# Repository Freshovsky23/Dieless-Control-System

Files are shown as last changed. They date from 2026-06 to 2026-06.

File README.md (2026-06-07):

# Dieless - Automated Wire Drawing Control System 🧵⚙️⚡

An advanced embedded control system designed for a **Dieless Wire Drawing Machine** engineering project. This system coordinates independent dual-stepper motor velocity profiles, features real-time analog micro-adjustments, and utilizes a complete local Human-Machine Interface (HMI).

Developed under the auspices of the **"CREATIVE" Student Science Club**.

---

## 📺 Project Presentation & Demo

Watch the system in action on YouTube:



*Click the badge above to watch the project implementation and physical mechanical execution details.*

---

## 🚀 System Features

* **High-Performance Jitter-Free Engine:** Implements a non-blocking microsecond phase-accumulation scheduler capable of driving dual A4988 stepper drivers independently without timing drift.
* **Velocity Profiling (Ramp Rate):** Integrated linear acceleration and deceleration profiling (2000 Hz/s rate) protecting motors from stalling or losing synchronization during sudden load changes.
* **Real-Time Trim Adjustment:** Dual-potentiometer sampling with 12-bit ADC mapping, providing a precision $\pm5\%$ velocity override overlay on-the-fly.
* **4x4 Matrix Keypad Configuration:** Full operational control board layout using an asynchronous multi-state input buffer for entering specific base frequencies (Hz).
* **Optimized I2C HMI Display:** Formatted 20x4 LCD frame architecture running on a high-speed 400kHz I2C bus clock to eliminate screen update blocking latencies.

---

## 🛠️ Hardware & PCB Design

The control system has been migrated from breadboard prototyping to a dedicated, custom-designed PCB tailored for high-frequency signal switching and heavy motor current distribution. 

### 📐 PCB View (3D Render)
The board architecture implements strict physical isolation between the high-current motor power rails (VMOT) and the sensitive analog/I2C traces to completely eliminate electromagnetic interference and noise injection.

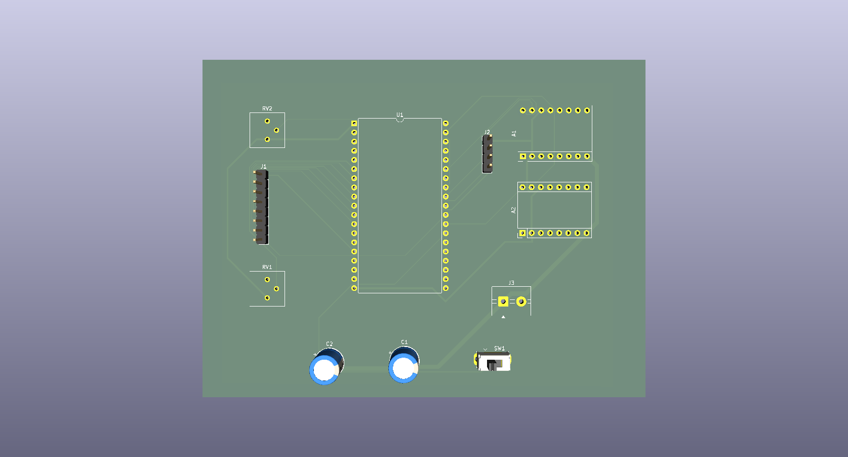
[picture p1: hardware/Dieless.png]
Dieless Control PCB 3D Render


---

## 🔌 Complete Hardware Pin Mapping (Pinout)

To ensure proper hardware replication, connect the peripheral components to the ESP32 microcontroller precisely as outlined in the engineering reference tables below:

### 1. Actuators & Control Interfaces
| ESP32 GPIO Pin | Component Peripheral | Hardware Functionality / Description | Suggested Track Width |
| :---: | :--- | :--- | :---: |
| **+5V / VIN** | Main Logic Rail | Core power for driver logic and LCD module | **0.50 mm** |
| **+3.3V** | Analog Rail | Clean reference voltage for ADC potentiometers | **0.50 mm** |
| **VMOT (24V)** | A4988 Power Supply | High-current power for stepper motor coils | 🔥 **1.20 mm** |
| **GND** | System Common | Solid Ground Plane (Bottom Copper Zone) | *Copper Zone* |
| **GPIO 18** | Stepper Driver 1 (A4988) | **STEP** – Motor 1 Pulse Generation Line (Wire Feeding) | 0.25 mm |
| **GPIO 19** | Stepper Driver 1 (A4988) | **DIR** – Motor 1 Directional Logic Level Control | 0.25 mm |
| **GPIO 23** | Stepper Driver 2 (A4988) | **STEP** – Motor 2 Pulse Generation Line (Wire Drawing) | 0.25 mm |
| **GPIO 16** | Stepper Driver 2 (A4988) | **DIR** – Motor 2 Directional Control (*Safe Non-Bootstrap Pin*) | 0.25 mm |
| **GPIO 34** | Potentiometer 1 | **Analog Input** – Motor 1 Real-time Speed Trim Override | 0.25 mm |
| **GPIO 35** | Potentiometer 2 | **Analog Input** – Motor 2 Real-time Speed Trim Override | 0.25 mm |
| **GPIO 4** | SPDT Toggle Switch | **Digital Input (Internal Pullup)** – Active Motor Selection Editor | 0.25 mm |

### 2. 4x4 Membrane Keypad Matrix Connections
| ESP32 GPIO Pin | Keypad Ribbon Pin | Matrix Row / Column Designation | Suggested Track Width |
| :---: | :---: | :--- | :---: |
| **GPIO 13** | Pin 1 | **ROW 1** (Handles keys: 1, 2, 3, A) | 0.25 mm |
| **GPIO 14** | Pin 2 | **ROW 2** (Handles keys: 4, 5, 6, B) | 0.25 mm |
| **GPIO 27** | Pin 3 | **ROW 3** (Handles keys: 7, 8, 9, C) | 0.25 mm |
| **GPIO 26** | Pin 4 | **ROW 4** (Handles keys: \*, 0, #, D) | 0.25 mm |
| **GPIO 25** | Pin 5 | **COL 1** (Handles keys: 1, 4, 7, \*) | 0.25 mm |
| **GPIO 33** | Pin 6 | **COL 2** (Handles keys: 2, 5, 8, 0) | 0.25 mm |
| **GPIO 32** | Pin 7 | **COL 3** (Handles keys: 3, 6, 9, #) | 0.25 mm |
| **GPIO 17** | Pin 8 | **COL 4** (Handles keys: A, B, C, D) | 0.25 mm |

### 3. Display Peripherals & Bus Communication
| ESP32 GPIO Pin | Module / Controller | Bus Line Designation | Suggested Track Width |
| :---: | :--- | :--- | :---: |
| **GPIO 21** | I2C LCD 20x4 (PCF8574) | **SDA** – Serial Data Communication Bus | 0.25 mm |
| **GPIO 22** | I2C LCD 20x4 (PCF8574) | **SCL** – Serial Clock Bus (Configured to 400kHz Fast Mode) | 0.25 mm |

---

## ⌨️ Control Panel HMI Reference

### Keypad 4x4 Layout Matrix

| Key | Core Function | Operational Description |
| :---: | :--- | :--- |
| **`0` – `9`** | **Numeric Entry** | Inputs target step frequency values (Safe bounded range: `0` – `9999` Hz). |
| **`D`** | **Direction Stage** | Toggles the pending rotational direction profile buffer layout between `[CW]` and `[CCW]`. |
| **`#`** | **ENTER / Commit** | Flushes the staged parameters, saving target velocity and setting hardware direction pins. |
| **`*`** | **Backspace** | Removes the terminal character from the active screen buffer string. |
| **`C`** | **Clear Buffer** | Instantly wipes the temporary keyboard data input buffer. |
| **`A`** | **START Machine** | Global execution trigger. Smoothly ramps up both stepper lines to target run frequencies. |
| **`B`** | **STOP Machine** | E-Stop equivalent software override. Instantly cuts execution pulses and triggers safe deceleration. |

### LCD 20x4 Screen Topology Reference
The user interface handles full frame updates seamlessly asynchronously. The display grid mapping topology layout runs as follows:

```text
+------------------------------------+
|M1: [BaseHz] |T:[Trim%] |[ActiveDir]| -> Line 1: Wire Feeding Motor Telemetry
|M2: [BaseHz] |T:[Trim%] |[ActiveDir]| -> Line 2: Wire Drawing Motor Telemetry
|Input: [EditorBuffer]   [PendingDir]| -> Line 3: Live Input HMI Keypad Buffer
|[MachineStatus] | Ed: [TargetMotor] | -> Line 4: System Operational Status
+------------------------------------+
📂 Repository Structure
Plaintext
├── firmware/              # ESP32 Core Control Source Code (C++/Arduino)
│   ├── src/
│   │   └── main.cpp
│   └── platformio.ini
├── hardware/              # KiCad EDA Project Files & Manufacturing Exports
│   ├── dieless-control.kicad_pro
│   ├── dieless-control.kicad_sch
│   ├── dieless-control.kicad_pcb
│   └── Dieless.png        # 3D Render preview of the custom PCB layout
└── README.md              # Main project documentation
👤 Author
Developer: @Freshovsky23

Contact: Heilman.Wiktor23@gmail.com

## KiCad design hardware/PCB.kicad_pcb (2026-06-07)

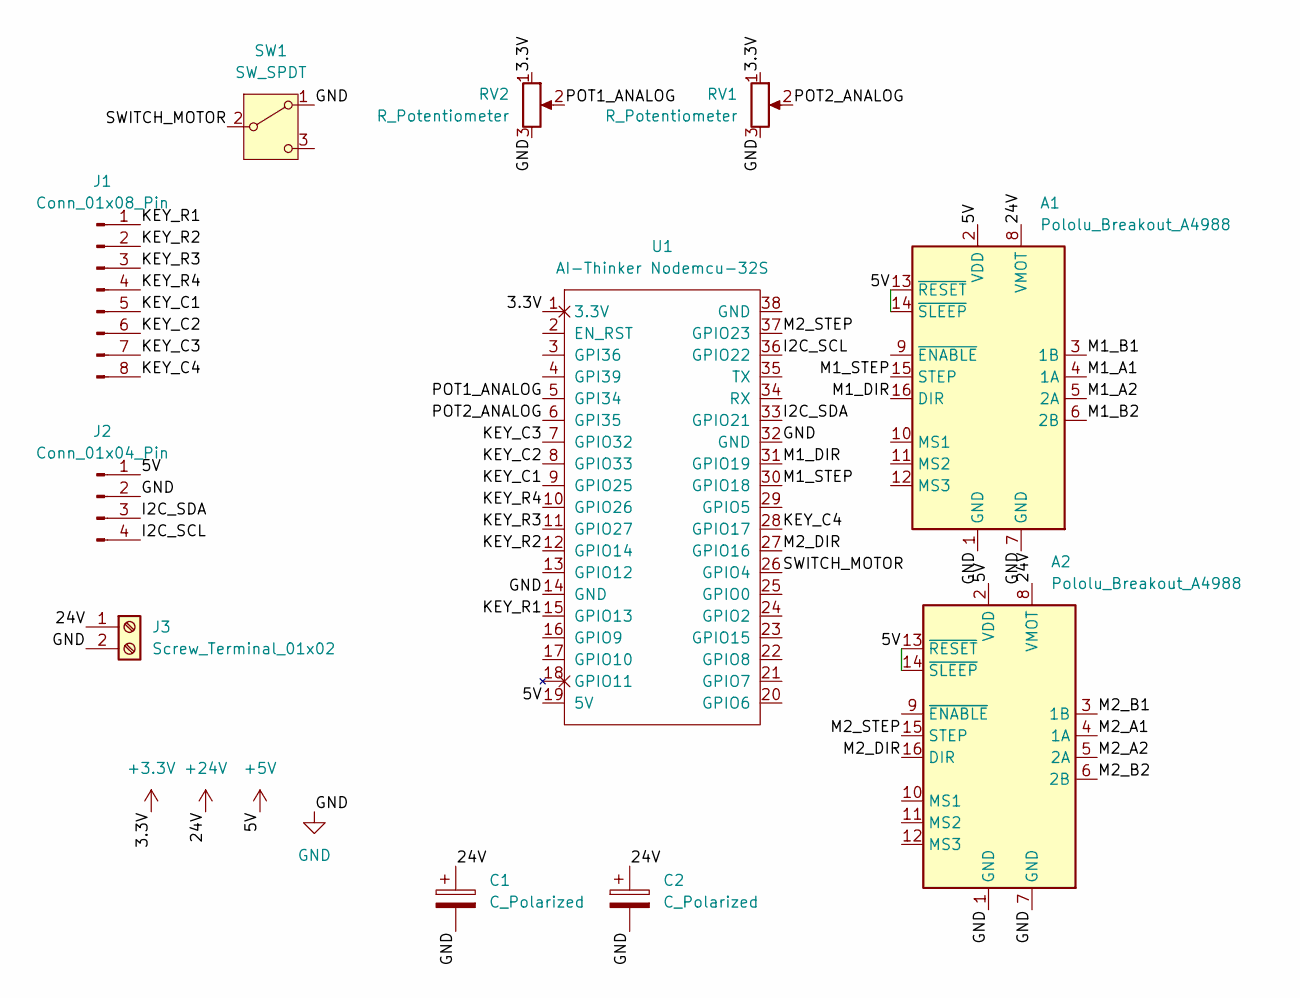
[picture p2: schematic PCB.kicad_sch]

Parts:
A1, A2: Pololu_Breakout_A4988; Pololu_Breakout-16_15.2x20.3mm
C1, C2: C_Polarized; CP_Radial_D8.0mm_P3.50mm
J1: Conn_01x08_Pin; PinHeader_1x08_P2.54mm_Vertical
J2: Conn_01x04_Pin; PinHeader_1x04_P2.54mm_Vertical
J3: Screw_Terminal_01x02; TerminalBlock_MaiXu_MX126-5.0-02P_1x02_P5.00mm
RV1, RV2: R_Potentiometer; Potentiometer_Bourns_3386P_Vertical
SW1: SW_SPDT; SW_Slide_SPDT_Straight_CK_OS102011MS2Q
U1: AI-Thinker Nodemcu-32S; ai-thinker nodemcu-32s

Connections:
+3.3V: RV1.1, RV2.1, U1.1 (3.3V)
+5V: A1.2 (VDD), A1.13 (~RESET), A1.14 (~SLEEP), A2.2 (VDD), A2.13 (~RESET), A2.14 (~SLEEP), J2.1, U1.19 (5V)
+24V: A1.8 (VMOT), A2.8 (VMOT), C1.1, C2.1, J3.1
/I2C_SCL: J2.4, U1.36 (GPIO22)
/I2C_SDA: J2.3, U1.33 (GPIO21)
/KEY_C1: J1.5, U1.9 (GPIO25)
/KEY_C2: J1.6, U1.8 (GPIO33)
/KEY_C3: J1.7, U1.7 (GPIO32)
/KEY_C4: J1.8, U1.28 (GPIO17)
/KEY_R1: J1.1, U1.15 (GPIO13)
/KEY_R2: J1.2, U1.12 (GPIO14)
/KEY_R3: J1.3, U1.11 (GPIO27)
/KEY_R4: J1.4, U1.10 (GPIO26)
/M1_A1: A1.4 (1A)
/M1_A2: A1.5 (2A)
/M1_B1: A1.3 (1B)
/M1_B2: A1.6 (2B)
/M1_DIR: A1.16 (DIR), U1.31 (GPIO19)
/M1_STEP: A1.15 (STEP), U1.30 (GPIO18)
/M2_A1: A2.4 (1A)
/M2_A2: A2.5 (2A)
/M2_B1: A2.3 (1B)
/M2_B2: A2.6 (2B)
/M2_DIR: A2.16 (DIR), U1.27 (GPIO16)
/M2_STEP: A2.15 (STEP), U1.37 (GPIO23)
/POT1_ANALOG: RV2.2, U1.5 (GPI34)
/POT2_ANALOG: RV1.2, U1.6 (GPI35)
/SWITCH_MOTOR: SW1.2 (B), U1.26 (GPIO4)
GND: A1.1 (GND), A1.7 (GND), A2.1 (GND), A2.7 (GND), C1.2, C2.2, J2.2, J3.2, RV1.3, RV2.3, SW1.1 (A), U1.14 (GND), U1.32 (GND)

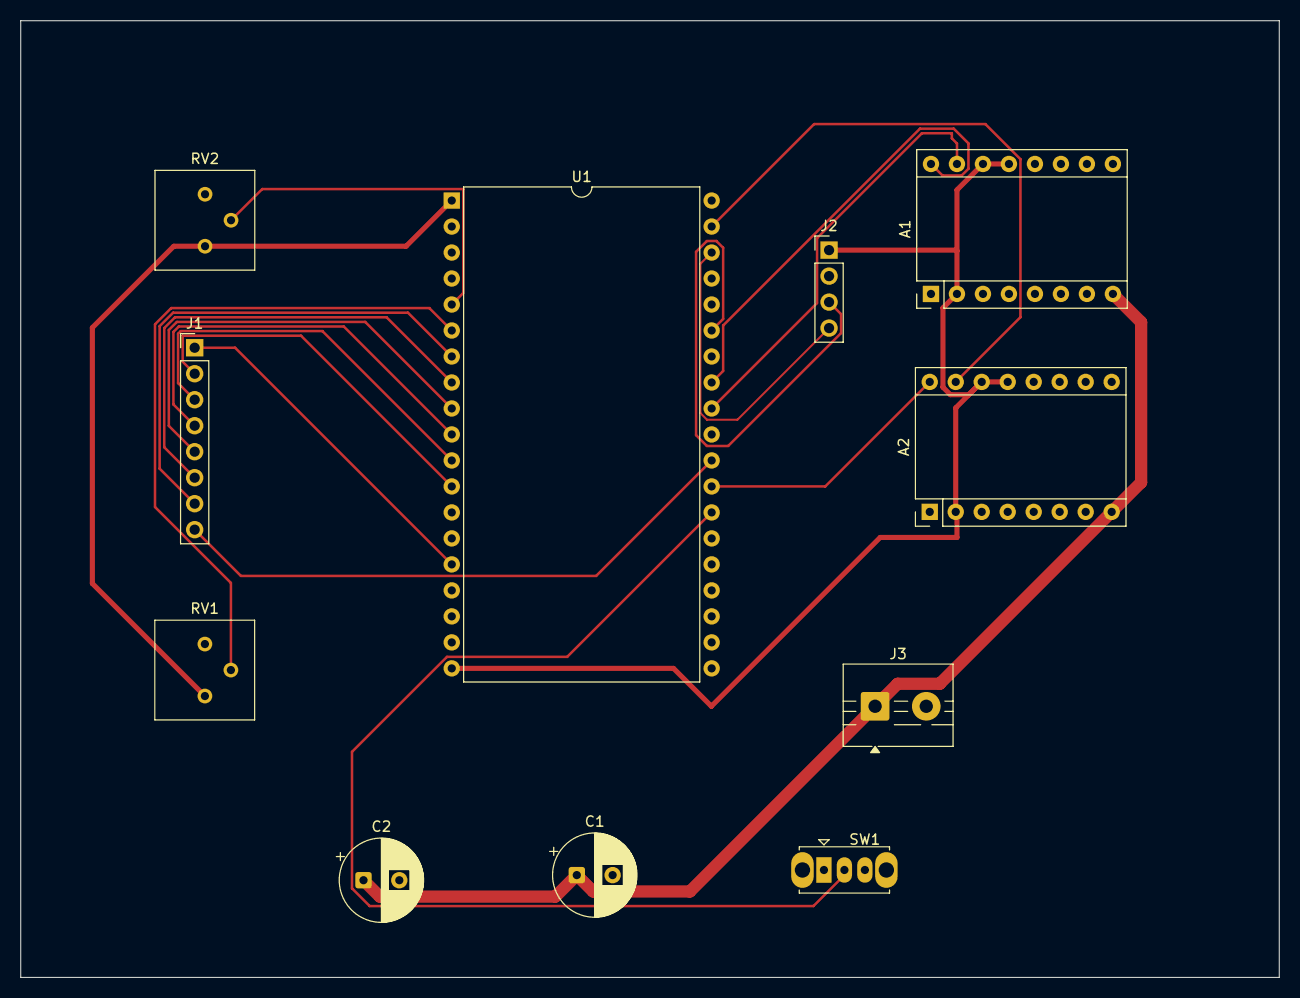
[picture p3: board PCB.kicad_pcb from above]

Board: 2 copper layers, 123.0 x 93.5 mm, 11 parts (0 on the bottom side), 21 nets.

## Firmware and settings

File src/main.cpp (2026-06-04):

#include <Arduino.h>           // Include the core Arduino framework libraries
#include <Wire.h>              // Include the I2C communication library for LCD control
#include <LiquidCrystal_I2C.h> // Include the library for I2C Liquid Crystal Displays
#include <Keypad.h>            // Include the matrix keypad interface library

// --- PIN CONFIGURATION ---
const int POT1_PIN = 34;       // Analog input pin for Potentiometer 1 (Motor 1 speed trim)
const int POT2_PIN = 35;       // Analog input pin for Potentiometer 2 (Motor 2 speed trim)
const int SWITCH_PIN = 4;      // Digital input pin for the motor selection toggle switch

const int STEP_PIN_1 = 18;     // Digital output pin for Motor 1 STEP signal (A4988 driver)
const int DIR_PIN_1  = 19;     // Digital output pin for Motor 1 DIRECTION signal (A4988 driver)
const int STEP_PIN_2 = 23;     // Digital output pin for Motor 2 STEP signal (A4988 driver)
const int DIR_PIN_2  = 16;     // Digital output pin for Motor 2 DIRECTION signal (GPIO16 replaces bootstrap GPIO5)

// --- 4x4 MEMBRANE KEYPAD CONFIGURATION ---
const byte ROWS = 4;           // Define the number of rows on the keypad matrix
const byte COLS = 4;           // Define the number of columns on the keypad matrix
char keys[ROWS][COLS] = {      // Define the key map layout corresponding to the physical matrix
  {'1','2','3','A'},           // Row 0 key definitions (Numbers 1-3, Command A -> START)
  {'4','5','6','B'},           // Row 1 key definitions (Numbers 4-6, Command B -> STOP)
  {'7','8','9','C'},           // Row 2 key definitions (Numbers 7-9, Command C -> CLEAR)
  {'*','0','#','D'}            // Row 3 key definitions (Backspace, Zero, Enter, Command D -> TOGGLE DIR)
};                             // End of keys matrix definition

byte rowPins[ROWS] = {13, 14, 27, 26}; // ESP32 GPIO pins connected to the keypad row lines
byte colPins[COLS] = {25, 33, 32, 17}; // ESP32 GPIO pins connected to the keypad column lines

Keypad keypad = Keypad(makeKeymap(keys), rowPins, colPins, ROWS, COLS); // Initialize Keypad instance with layout and pins
LiquidCrystal_I2C lcd(0x27, 20, 4);                                    // Initialize LCD instance at I2C address 0x27, 20x4 characters

// --- PROCESS VARIABLES ---
int baseV1 = 500;              // Target base frequency for Motor 1 in Hz (Steps per second)
int baseV2 = 500;              // Target base frequency for Motor 2 in Hz (Steps per second)
String inputBuffer = "";       // String buffer to accumulate numeric characters from the keypad

bool targetDir1 = true;        // Hardware direction state for Motor 1 (true = CW / HIGH, false = CCW / LOW)
bool targetDir2 = true;        // Hardware direction state for Motor 2 (true = CW / HIGH, false = CCW / LOW)
bool bufferDir  = true;        // Staged/pending direction state for the currently selected motor inside the editor

bool systemRunning = false;    // Global execution flag tracking machine state (false=STOP, true=RUN)
bool prevRunning   = false;    // Flag storing previous execution state to detect positive edge trigger
int prevSwitchState = -1;      // Variable to track changes in the hardware toggle switch state

// --- ACCELERATION / DECELERATION RAMP ---
int currentV1 = 0;             // Instantaneous velocity profile step for Motor 1 (Hz)
int currentV2 = 0;             // Instantaneous velocity profile step for Motor 2 (Hz)
const int RAMP_STEP        = 10; // Velocity delta increment per ramp execution interval (Hz)
const int RAMP_INTERVAL_MS = 5;  // Fixed millisecond interval separating velocity ramp step updates
unsigned long lastRampTime = 0; // Timestamp tracking the last millisecond execution of the ramp logic

// --- NON-BLOCKING TIMERS ---
unsigned long lastDisplayUpdate = 0; // Timestamp tracking the last millisecond update of the LCD interface
unsigned long lastStepTime1     = 0; // Timestamp tracking the exact microsecond execution of Motor 1's last step
unsigned long lastStepTime2     = 0; // Timestamp tracking the exact microsecond execution of Motor 2's last step

// Converts step frequency (Hz) to a non-blocking pulse period interval in microseconds
unsigned long speedToInterval(int speedHz) {
    if (speedHz <= 0) return 0;      // Return zero interval if target velocity is non-positive to stall motor
    return 1000000UL / speedHz;      // Calculate microsecond period using Unsigned Long literal to prevent overflow
}                                    // End of speedToInterval function

// ─────────────────────────────────────────────────────────────────────────────
void setup() {                       // Hardware and peripheral initialization phase
    Serial.begin(115200);            // Open hardware serial port at high-speed 115200 baud for debugging

    pinMode(POT1_PIN,   INPUT);      // Configure Potentiometer 1 pin as high-impedance analog input
    pinMode(POT2_PIN,   INPUT);      // Configure Potentiometer 2 pin as high-impedance analog input
    pinMode(SWITCH_PIN, INPUT_PULLUP); // Configure toggle switch pin with internal pull-up resistor active

    pinMode(STEP_PIN_1, OUTPUT);     // Configure Motor 1 step line as digital push-pull output
    pinMode(DIR_PIN_1,  OUTPUT);     // Configure Motor 1 direction line as digital push-pull output
    pinMode(STEP_PIN_2, OUTPUT);     // Configure Motor 2 step line as digital push-pull output
    pinMode(DIR_PIN_2,  OUTPUT);     // Configure Motor 2 direction line as digital push-pull output

    digitalWrite(DIR_PIN_1, targetDir1 ? HIGH : LOW); // Write default rotational direction to Motor 1 driver hardware
    digitalWrite(DIR_PIN_2, targetDir2 ? LOW : HIGH); // HARDWARE FIX: Inverted Motor 2 pin mapping to synchronize direction

    lcd.init();                      // Wake up and execute internal initialization routine for the I2C LCD
    lcd.backlight();                 // Enable the LED backlight power rail on the LCD module

    Wire.setClock(400000);           // Increase I2C bus speed to 400kHz to minimize blocking overhead during step cycles

    lcd.setCursor(0, 0); lcd.print("V1:      |T:    |    "); // Render static template framework for Line 0 (Speed, Trim, Direction)
    lcd.setCursor(0, 1); lcd.print("V2:      |T:    |    "); // Render static template framework for Line 1 (Speed, Trim, Direction)
    lcd.setCursor(0, 2); lcd.print("Input:              "); // Clear template line 2 to prevent double brackets
    lcd.setCursor(0, 3); lcd.print("STOP| Ed: ----------"); // Render static template framework for Line 3 (System Status + selection)
}                                    // End of setup function

// ─────────────────────────────────────────────────────────────────────────────
void loop() {                        // Main cyclical program execution thread
    char key         = keypad.getKey();         // Poll the keypad matrix controller for asynchronous key press events
    int  switchState = digitalRead(SWITCH_PIN); // Read physical toggle switch state (LOW = Motor 1, HIGH = Motor 2)

    // ── SWITCH STATE MONITORING & BUFFER SYNC ─────────────────────────────
    if (switchState != prevSwitchState) {       // Evaluate if the operator flipped the physical toggle switch
        bufferDir = (switchState == LOW) ? targetDir1 : targetDir2; // Sync staged buffer direction variable to selected motor's active state
        prevSwitchState = switchState;          // Update switch state memory flag to catch subsequent hardware state changes
    }                                           // End of switch state synchronization context

    // ── KEYPAD CONTROLLER LOGIC ──────────────────────────────────────────
    if (key) {                                  // Evaluate if a valid key press event occurred during polling
        if (key >= '0' && key <= '9') {         // Verify if the incoming character resides within numeric ranges
            if (inputBuffer.length() < 4) inputBuffer += key; // Append numeric character if buffer is under 4-digit limit
        }                                       // End of numeric validation filter
        else if (key == 'D') {                  // Intercept command key 'D' designated to handle pending direction inversion
            bufferDir = !bufferDir;             // Electronically toggle the pending directional state inside the editor buffer
        }                                       // End of direction toggle processing
        else if (key == '#') {                  // Intercept hash key designated as ENTER command to submit staged parameters
            if (inputBuffer.length() > 0) {     // Ensure input buffer contains numeric data prior to executing memory commit
                int val = inputBuffer.toInt();  // Parse raw buffer string data into signed integer frequency metric
                if (switchState == LOW) baseV1 = val; // Apply target parsed metric to Motor 1 if toggle points LOW
                else                   baseV2 = val; // Apply target parsed metric to Motor 2 if toggle points HIGH
                inputBuffer = "";               // Flush input string buffer to receive subsequent inputs cleanly
            }                                   // End of active numeric buffer condition
            
            if (switchState == LOW) {           // Execute parameters processing branch dedicated to Motor 1 hardware profile
                targetDir1 = bufferDir;         // Transfer staged buffer directional parameter into actual active variable
                digitalWrite(DIR_PIN_1, targetDir1 ? HIGH : LOW); // Write the standard physical logic state to DIR_1 hardware pin
            } else {                            // Intercept parameters processing branch dedicated to Motor 2 hardware profile
                targetDir2 = bufferDir;         // Transfer staged buffer directional parameter into actual active variable
                digitalWrite(DIR_PIN_2, targetDir2 ? LOW : HIGH); // HARDWARE FIX: Inverted output matching software abstraction layer
            }                                   // End of directional hardware assignment filter
        }                                       // End of ENTER command processing
        else if (key == '*') {                  // Intercept asterisk key designated as BACKSPACE command
            if (inputBuffer.length() > 0)       // Confirm buffer is populated prior to attempting deletion cycle
                inputBuffer.remove(inputBuffer.length() - 1); // Delete terminal character from string buffer sequence
        }                                       // End of BACKSPACE command processing
        else if (key == 'C') {                  // Intercept alpha key 'C' designated as absolute CLEAR command
            inputBuffer = "";                   // Instantly wipe and reinitialize the input buffer contents
        }                                       // End of CLEAR command processing
        else if (key == 'A') {                  // Intercept alpha key 'A' designated as system START directive
            systemRunning = true;               // Set global run-state machine flag to enable motor driver tasks
        }                                       // End of START command processing
        else if (key == 'B') {                  // Intercept alpha key 'B' designated as system STOP directive
            systemRunning = false;              // Reset global run-state machine flag to halt motor driver tasks
        }                                       // End of STOP command processing
    }                                           // End of keypad processing condition

    // ── RUNTIME TIMER SYNCHRONIZATION ─────────────────────────────────────
    if (systemRunning && !prevRunning) {         // Monitor positive edge switch to detect the exact moment system triggers RUN
        unsigned long now = micros();            // Capture stable snapshot reference of internal system time counter
        lastStepTime1 = now;                     // Synchronize Motor 1 scheduler timer to current time snapshot
        lastStepTime2 = now;                     // Synchronize Motor 2 scheduler timer to current time snapshot
        lastRampTime  = millis();                // Synchronize acceleration profile timer to millisecond clock
    }                                           // End of positive edge conditional synchronization
    prevRunning = systemRunning;                // Cache state flag to compute differential transitions on future passes

    // ── POTENTIOMETER ANALOG SAMPLING ──────────────────────────────────────
    int pot1Raw = analogRead(POT1_PIN);         // Sample 12-bit ADC voltage channel mapped to Potentiometer 1 (0-4095)
    int pot2Raw = analogRead(POT2_PIN);         // Sample 12-bit ADC voltage channel mapped to Potentiometer 2 (0-4095)
    int trim1   = map(pot1Raw, 0, 4095, -5, 5); // Map raw 12-bit values linearly to integer trim percentage (-5% to +5%)
    int trim2   = map(pot2Raw, 0, 4095, -5, 5); // Map raw 12-bit values linearly to integer trim percentage (-5% to +5%)

    // ── TARGET VELOCITY CALCULATION ────────────────────────────────────────
    int finalV1 = constrain(baseV1 + (baseV1 * trim1 / 100), 0, 9999); // Compute and clamp absolute target velocity for Motor 1
    int finalV2 = constrain(baseV2 + (baseV2 * trim2 / 100), 0, 9999); // Compute and clamp absolute target velocity for Motor 2

    // ── ACCELERATION / DECELERATION PROFILER ───────────────────────────────
    if (systemRunning) {                        // Execute step-wise velocity profiles only when machine state is active
        if (millis() - lastRampTime >= (unsigned long)RAMP_INTERVAL_MS) { // Check if velocity profiling cycle interval has expired
            lastRampTime = millis();            // Reset the millisecond timestamp baseline tracking the profiling loop
            currentV1 = (currentV1 < finalV1) ? min(currentV1 + RAMP_STEP, finalV1)   // Accelerate or cap Motor 1 profile speed
                                               : max(currentV1 - RAMP_STEP, finalV1);  // Decelerate or floor Motor 1 profile speed
            currentV2 = (currentV2 < finalV2) ? min(currentV2 + RAMP_STEP, finalV2)   // Accelerate or cap Motor 2 profile speed
                                               : max(currentV2 - RAMP_STEP, finalV2);  // Decelerate or floor Motor 2 profile speed
        }                                       // End of profiling tick interval processing
    } else {                                    // Intercept inactive machine states to reset acceleration structures
        currentV1 = 0;                          // Reset current operational step frequency of Motor 1 instantly to zero
        currentV2 = 0;                          // Reset current operational step frequency of Motor 2 instantly to zero
    }                                           // End of run-state velocity profiling check

    unsigned long stepInterval1 = speedToInterval(currentV1); // Convert current ramp speed into microsecond phase ticks for Motor 1
    unsigned long stepInterval2 = speedToInterval(currentV2); // Convert current ramp speed into microsecond phase ticks for Motor 2

    // ── STEP PULSE GENERATION SCHEDULER (NON-BLOCKING) ─────────────────────
    if (systemRunning) {                        // Authorize low-level stepper driver execution blocks under execution state
        unsigned long currentMicros = micros(); // Capture high-resolution microsecond timer update for task tracking

        // MOTOR 1 STEP EXECUTION TASK
        if (stepInterval1 > 0 && (currentMicros - lastStepTime1 >= stepInterval1)) { // Evaluate if phase period for Motor 1 has completed
            if (currentMicros - lastStepTime1 > stepInterval1 * 2UL) {               // Detect overflow latency exceeding double execution bounds
                lastStepTime1 = currentMicros - stepInterval1;                       // Drop accumulative backlog and bind scheduler to clear latency
            } else {                                                                 // Normal scheduling flow with no execution backlog present
                lastStepTime1 += stepInterval1;                                      // Advance phase timing boundary precisely without temporal drift
            }                                                                        // End of backlog protection filter evaluation
            digitalWrite(STEP_PIN_1, HIGH);     // Assert high state on Motor 1 driver step line to trigger internal driver circuit
            delayMicroseconds(10);              // Maintain pulse shape width duration for safe driver input registration
            digitalWrite(STEP_PIN_1, LOW);      // Clear step line back to low state to complete square wave generation pass
        }                                       // End of Motor 1 scheduler check

        // MOTOR 2 STEP EXECUTION TASK
        currentMicros = micros();               // Force-refresh timer reference to exclude delayMicroseconds overhead from Motor 1 pass
        if (stepInterval2 > 0 && (currentMicros - lastStepTime2 >= stepInterval2)) { // Evaluate if phase period for Motor 2 has completed
            if (currentMicros - lastStepTime2 > stepInterval2 * 2UL) {               // Detect overflow latency exceeding double execution bounds
                lastStepTime2 = currentMicros - stepInterval2;                       // Drop accumulative backlog and bind scheduler to clear latency
            } else {                                                                 // Normal scheduling flow with no execution backlog present
                lastStepTime2 += stepInterval2;                                      // Advance phase timing boundary precisely without temporal drift
            }                                                                        // End of backlog protection filter evaluation
            digitalWrite(STEP_PIN_2, HIGH);     // Assert high state on Motor 2 driver step line to trigger internal driver circuit
            delayMicroseconds(10);              // Maintain pulse shape width duration for safe driver input registration
            digitalWrite(STEP_PIN_2, LOW);      // Clear step line back to low state to complete square wave generation pass
        }                                       // End of Motor 2 scheduler check
    }                                           // End of non-blocking step engine logic block

    // ── GRAPHICAL LCD HMI DISPLAY TASK (150MS REFRESH RATE) ────────────────
    if (millis() - lastDisplayUpdate > 150) {   // Assess if display window refresh rate delay has elapsed
        lastDisplayUpdate = millis();           // Reset display refresh timer milestone tracking structure

        // LINE 0 INTERFACE: Motor 1 Operational State
        lcd.setCursor(3, 0);                    // Relocate I2C text layout cursor boundary to numerical slot position on Line 0
        lcd.print(baseV1);                      // Transmit numerical base velocity string representation to LCD screen
        if      (baseV1 < 10)   lcd.print("   "); // Pad single-digit string values cleanly with three blank trailing characters
        else if (baseV1 < 100)  lcd.print("  ");  // Pad double-digit string values cleanly with two blank trailing characters
        else if (baseV1 < 1000) lcd.print(" ");   // Pad triple-digit string values cleanly with one blank trailing character

        lcd.setCursor(11, 0);                   // Relocate text cursor layout boundary to trim slot position on Line 0
        if (trim1 >= 0) lcd.print("+");         // Append positive operational indicator character if mapped value is positive or zero
        lcd.print(trim1);                       // Transmit raw computed numerical integer trim metric to display screen
        lcd.print("%");                         // Append standard dimensional percentage indicator array block

        lcd.setCursor(16, 0);                   // Shift cursor focus towards the dedicated hardware direction output zone
        lcd.print(targetDir1 ? "CW  " : "CCW "); // Render alphanumeric tag reflecting active physical directional status

        // LINE 1 INTERFACE: Motor 2 Operational State
        lcd.setCursor(3, 1);                    // Relocate I2C text layout cursor boundary to numerical slot position on Line 1
        lcd.print(baseV2);                      // Transmit numerical base velocity string representation to LCD screen
        if      (baseV2 < 10)   lcd.print("   "); // Pad single-digit string values cleanly with three blank trailing characters
        else if (baseV2 < 100)  lcd.print("  ");  // Pad double-digit string values cleanly with two blank trailing characters
        else if (baseV2 < 1000) lcd.print(" ");   // Pad triple-digit string values cleanly with one blank trailing character

        lcd.setCursor(11, 1);                   // Relocate text cursor layout boundary to trim slot position on Line 1
        if (trim2 >= 0) lcd.print("+");         // Append positive operational indicator character if mapped value is positive or zero
        lcd.print(trim2);                       // Transmit raw computed numerical integer trim metric to display screen
        lcd.print("%");                         // Append standard dimensional percentage indicator array block

        lcd.setCursor(16, 1);                   // Shift cursor focus towards the dedicated hardware direction output zone
        lcd.print(targetDir2 ? "CW  " : "CCW "); // Render alphanumeric tag reflecting active physical directional status
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

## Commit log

2026-06-07 feat: add initial KiCad schematic and PCB layout design
    [PCB.kicad_pcb, PCB.kicad_sch]
2026-06-07 Revise README with new features and PCB design details
    Updated README.md to enhance clarity and add new sections.
